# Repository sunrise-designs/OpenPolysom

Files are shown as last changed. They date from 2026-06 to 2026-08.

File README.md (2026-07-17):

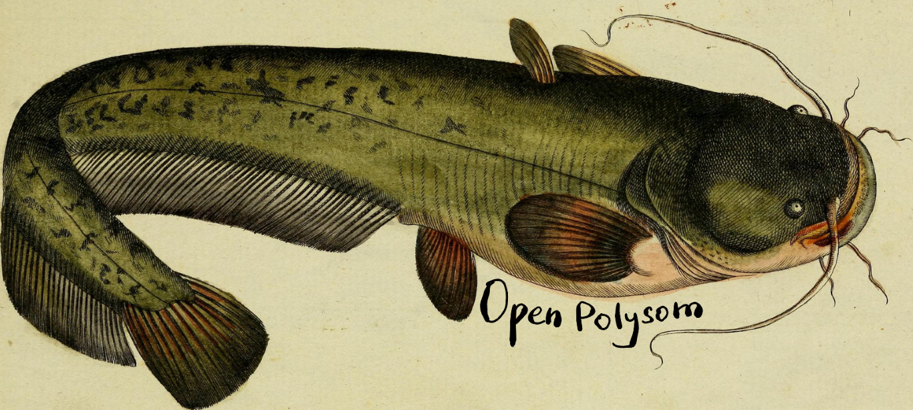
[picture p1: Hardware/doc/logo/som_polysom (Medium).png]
OpenPolysom


OpenPolysom
===========================

This is an open-source Polysomnography (PSG) physical device and analysis software. It performs what is know as a sleep study.

It runs on an ESP32 microcontroller, and collects these signals from a patient:
- [Respiratory Inductance Plethysmography (RIP)](#baseline-removal-from-the-rip-signal---the-chest-belts)
- [Nasal air flow rate](#air-flow-signal-processing)
- RR intervals (heart rate)
- Sound recording for [snoring detection](#snoring-classification-and-feature-extraction)
- Acceleration data from the leg sensors to [detect leg twitching](#accelerometer-data-processing)

New! Some real recordings:
===========================
[A somewhat truncated 2 hours of real sleep data - 17 July 2026](https://polysom.netlify.app/index.html?meta=studies%2Fbiometric_2026-07-16_23-00-00%2Fmeta.json)

Why do this?
===========================
It's about creating an _accessible, rapid_ diagnostic pathway for sleep disorders. Many, many people suffer from sleep disorders, breathing-related ones in particular. They have a significant effect on the quality of life, safety (falling asleep while driving) and serious long-term adverse health effects.
The current diagnostic process is abysmally slow on the NHS. There are private routes, but they are financially prohibitive for most.

It's hard to diagnose because:
- Most of the time, the sufferer is unaware of the problem (they only know they are groggy and tired)
- Partners don't know how to tell "normal" snoring, if there's such a thing, from a serious breathing-related sleep disorder
- It's seen as a "specialist" subject in the NHS, and GPs receive hardly any training in this field. They are quick to dismiss fatigue-related complaints
- Even once the person starts looking for a cause, the different avenues to explore are bewildering, expensive, and full of marketing hype
- There is not a streamlined diagnostic pathway, or "one-size-fits-all" solution, because of individual anatomy, neurological comorbidities, lifestyle and so on

What does this aim to do?
===========================
Firstly, this is not a replacement for a qualified medical opinion and treatment.
However, this seeks to:
- Raise awareness. There's not enough awareness around the variety of sleep disorders in the population. There have been huge campaigns around cancers, heart health (which is fantastic), but not this, yet
- Open source, forever. The main, explicit intention of this project is to always remain fully open source, software and hardware
  This means that anyone with enough knowledge can look at data, contribute, validate and build the OpenPolysom
- It aims to be simple enough for a layman to use, but powerful enough for advanced research and clinical diagnostics
- Affordable. There are great polysomnography solutions out there, sure. But they are very expensive, proprietary, and generally only accessible to
state healthcare systems or private clinics. The goal of this project is to be financially affordable to anyone

What is this going to look like?
===========================
The eventual goal is to have an easy-to-use, reusable, affordable polysomnography device and diagnostic infrastructure.
- A patient receives the device, or even builds it themselves
- They wear it for one or more nights
- Quality pre-processed data is recorded onto the device (removable SD card)
- There could be a few ways to analyze the data:
    - Send it to a specialist doctor or a clinician
    - Ask for advice on peer-to-peer forums like Apnea Board
    - Some combination of local and cloud-based algorithm can detect features of a number of breathing-related sleep disorders, like Obstructive Apnea, Central Apnea, UARS, and so on
- The strength of this project is pulling together various bits of science which are out there, but disjoint and difficult to find and use. It aims to make a comprehensive assessment of the data, find a possible problem (if any) and at least suggest possible treatment pathways. This is in no way a substitute for qualified medical advice.

How can it detect sleep disorders?
===========================
It a basic level, it's not so difficult! (The following is a simplified version!)

- If you're snoring away, then you stop, your chest belts show that you are "paradoxically breathing", in other words heaving for air, but there's no airflow - you might have Obstructive Apnea. You tongue or soft palate have collapsed backwards and blocked your airway. Your blood oxygen will also drop.
- There's no airflow, _and_ the chest belts show no movement. Your brain simply "forgot" to breathe! That's Central Apnea. Your blood oxygen wil also drop.
- Your blood oxygen does not drop appreciably, but your heart rate spikes significantly at times during your sleep. Your body has become quite sensitive to "breathing effort", and even though your airway isn't fully obstructed, your sleep is fragmented enough to make you feel terrible. This might be Upper Airway Resistance Syndrome (UARS). You might a completely "healthy" score on an official sleep apnea scale, but this is still a very serious problem!
- Your breathing might be fine, but you twitch lots in your sleep (this can be detected by an accelerometer). This could be Periodic Limb Movement Disorder (PLMD). This can also make you feel very tired.
- You might have none of the above, but you wake up gasping, talking and screaming in your sleep. You might be suffering from nightmares!
- And so on!

The point it, it takes a confluence of all the different signals recorded by the polysomnography device to steer the diagnosis in the correct direction. Recording just one or two things usually is not enough.

Challenges to solve
===========================
## Medical device compliance

There is no getting around the fact that this is a Medical Device, likely class B. There is no point in simply providing a heap of dry statistics and numerical metrics from the recorded signals - 99% of users without a very specialist skill set would not be able to interpret them. This isn't a "wellness" device. The interpretation is the whole point of the OpenPolysom, being able to cautiously point the user in the right direction on their path to the eventual resolution of their sleep problems.
This lands it firmly in the regulated territory. Therefore, this system, software and hardware alike, will be designed with IEC 62304 (Medical Software) in mind. The intent is to keep the code which extracts the dry metrics completely separate from the code which makes any interpretation of those metrics.

## Accelerometer data processing
I am currently using two accelerometers attached near the ankle to both legs to detect leg twitching and decide whether PLMS (Periodic Limb Movements of Sleep) or PLMD (Periodic Limb Movement Disorder) is present. The American Academy of Sleep Medicine (AASM) scoring criteria are fairly straightforward to interpret, but for an accurate count the acceleration due to twitching (sudden movement followed by return to the same leg position) should be distinguished from the acceleration due to the position change. This will be determined by the angle between the two baseline positions $q1$ and $q2$: $\Delta q = q_2 \otimes q_1^{-1}$ being below a certain threshold. (note: for advanced clinical studies, Leg Movement events are detected with Electromyography (EMG), because isometric contractions which do not result in physical movement also count. The accelerometers is a temporary proxy which is easier to setup and more robust)

## Baseline removal from the RIP signal - the chest belts

The plan is to achieve that using a combination of Qualitative Diagnostic Calibration (QDC) variant (Marvin Sackner, 1989) and Adaptive Iteratively Reweighted Penalized Least Squares (airPLS)

## Snoring classification and feature extraction

The end game would be to achieve accurate classification of anatomical snoring site according to the VOTE (Velum, Oropharynx, Tongue base, and Epiglottis). This could be achieved using MFCC/Mel feature extraction, then a fast real time ML model trained on the MPSSC (Munich-Passau Snore Sound Corpus) data.

## Air flow signal processing

I have not yet recorded a sample signal, but I am guessing there will be pretty standard noise filtering involved

The wiki — an LLM-first knowledge base
===========================
The in-depth documentation lives in an **LLM wiki**: a structured knowledge base written first for AI coding agents to read as working context, and second for humans. It is deliberately [`llms.txt`](https://llmstxt.org/)-shaped — a curated *map* of the project (architecture, data formats, signal processing, settled decisions, roadmap, coding standards) rather than an exhaustive dump — so an agent (or a person) reads the index first and then opens only the pages a task needs. The same Markdown is browsable as a website.

- **Browse it online:** https://sunrise-designs.github.io/OpenPolysom/
- **Read the source:** [`wiki/INDEX.md`](wiki/INDEX.md) — start here
- **Jump straight in:** [architecture](wiki/knowledge/architecture.md) · [data formats](wiki/knowledge/data-formats.md) · [roadmap](wiki/state/roadmap.md)

The Markdown in [`wiki/`](wiki) is rendered to a static site with [Quartz](https://quartz.jzhao.xyz/) and published to GitHub Pages (build: [`web/build.sh`](web/build.sh)).

What hardware does this expect
----------------------------
The hardware is currently a breadboard prototype, however a custom PCB is being developed in Kicad. See [hardware](/Hardware) folder.

The breadboard features (for now)
- LDC1612 inductance-to-frequency sensor on I2C bus with address 0x2B
- SDP800-125Pa Digital DP sensor (±125 Pa) (I2C address 0x25 or 0x26)
- Two MMA8451 accelerometers (with different I2C addresses)
- Polar H9 heart rate sensor via BLE

How to build
----------------------------
This is work in progress as project is developing fast.

The basic dependencies are:
- Python
- npm
- esp-idf (v 6.0 onwards)
- Rust (upcoming)

How to use
----------------------------
See this [brief guide](how%20to%20use.md)

Why a Som?
===========================
"Som" is a shorthand for polysomnography, and "Som" in Russian is a Wels catfish, _Silurus glanis_. I think it looks cool and terrifying in equal measure. Its whiskers also make me think of all the various probes and electrodes which feature on a polysomnography machine.

Disclaimer
===========================
This software is for informational and educational purposes only. It is not a medical device and is not intended to diagnose, treat, cure, or prevent any disease or sleep disorder.

Not Professional Advice: The outputs generated by this software should not be used as a substitute for professional medical advice, diagnosis, or treatment.

Consult a Physician: Always seek the advice of a qualified healthcare provider with any questions you may have regarding a medical condition.

No Liability: The developers and contributors provide this software "as is" and are not responsible for any actions taken based on its results.

References and inspiration
===========================
This software uses (heavily modified)
https://github.com/Seeed-Studio/Seeed_LDC1612

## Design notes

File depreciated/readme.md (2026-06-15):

Moving Windows-related stuff here. Because the code is running on Raspberry Pi, I don't want to spend time supporting Windows, for now, as Linux is a much better fit for this

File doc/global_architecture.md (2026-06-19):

There are two main components to this project:
1. Hardware data acquisition. It runs on a bespoke PCB board with ESP32-S3 microcontroller (WIFI/BLE/512KB SRAM, 384KB ROM, 8MB PSRAM, 8MB Flash memory)
2. Mixed local and cloud-based signal processing and visualization

I need help to decide on the architecture and data flow of the component 2, the data pipeline once it leaves the device.

The plan so far is:
1. ESP32 saves the various sampled signals (heart rate, sound, breathing, movement, EEG, etc) to an SD card. A simple proprietary binary format, which minimizes SD Card FTL Thrashing, will be used. The embedded code will be in C++
2. A python codebase ingests the binary data, and saves it to an intermediate format: Zarr binary file for high-density data, and a sidecar .json file for sparse metadata (like patient data, time of the experiment, settings and so on). Minimum processing happens at this stage.
3. In a second step, a signal processing Python codebase performs signal analysis on the data. This could become quite complex, incorporating elaborate DSP, and possibly ML and AI components. This will be the heart of the Polysom, it must be tightly version controlled, unit tested, and auditable. It will save the processed results to a new Zarr file (so that the raw data is preserved for auditability) and the results metadata .json file.
4. A Typescript codebase generates a web page which displays the charts via Apache ECharts, using HTTP Range Requests to enable responsive viewing of large datasets, and the associated metadata from the sidecar .json file(s)

Questions:
1. Does this sound sane?
2. Is ECharts the best option? Is there anything better/more performant/easier to use? Code Maintainability is very important.
2. Report generation in .pdf file format is very important. The current trade-off is to save the charts in a raster format, and combine them into a structured .pdf file where the metadata is selectable, bookmarked, and search-able. What are other potential options for this, if better ones exit?
3. This needs to be cross-platform as much as possible
3. Ideally, this should run locally, as well as on the web, in an air-gapped environment. Can the required infrastructure for this data flow (Python + packages, npm, etc) be realistically packaged into Windows, Linux and Mac installers?

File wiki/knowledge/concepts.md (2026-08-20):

---
title: PSG & Pipeline Concepts (Glossary)
domain: knowledge
status: living
updated: 2026-08-20
summary: A concise glossary of the polysomnography, sleep-disorder, signal and data-tech terms used across the ProtoSom wiki and codebase.
---

# PSG & Pipeline Concepts

A working glossary for ProtoSom. It defines the sleep-medicine terms behind the
signals we capture and the data-tech terms behind how we store and show them.
For *what we do* with these, see [signal processing](signal-processing.md),
[data formats](data-formats.md), [hardware](hardware.md) and the
[viewer](viewer.md); for *why* a thing is the way it is, see
[decisions](../state/decisions.md).

---

## Polysomnography (PSG)

**Polysomnography (PSG)** — a multi-signal sleep study: recording several
physiological channels simultaneously through a night's sleep so that breathing,
cardiac, movement and (here) acoustic events can be scored together. ProtoSom is
an open-source proof-of-concept PSG; no single channel diagnoses anything — it
takes a *confluence* of signals to steer a finding (`README.md:62`). It is
**not a medical device** (`README.md:134`).

The signals ProtoSom records ([hardware](hardware.md), `README.md:8`):
Respiratory Inductance Plethysmography (RIP, two belts), nasal airflow, heart
rate + RR intervals, wrist accelerometry, and audio for snore analysis.

---

## Sleep disorders & respiratory events

These are the *findings* the [Python processing](signal-processing.md) aims to
surface from the captured signals. Plain-language sketches per `README.md:51-60`.

- **Apnea** — a near-total cessation of airflow (conventionally ≥10 s in adults).
  Classified by what the RIP belts show:
  - **Obstructive apnea (OSA)** — *no airflow but the chest/abdomen belts still
    move*, often in opposite phase ("paradoxical breathing") as the body heaves
    against a collapsed upper airway (tongue/soft palate). Blood O₂ drops.
  - **Central apnea (CSA)** — *no airflow and no belt movement*: the drive to
    breathe is absent ("the brain forgot to breathe"). Blood O₂ drops.
  - **Mixed apnea** — a single event that begins central (no effort) and becomes
    obstructive (effort returns against a blocked airway), or vice versa.
- **Hypopnea** — a *partial* reduction in airflow (commonly ≥30% drop) sustained
  ≥10 s, paired with an O₂ desaturation and/or an arousal. The graded cousin of
  an apnea.
- **RERA (Respiratory Effort-Related Arousal)** — increasing breathing effort
  that ends in a cortical arousal but does **not** meet apnea/hypopnea
  thresholds. Visible as effort climbing on the RIP belts with airflow only
  mildly reduced.
- **UARS (Upper Airway Resistance Syndrome)** — repeated RERAs fragmenting sleep
  with *little or no O₂ desaturation*; the body becomes hypersensitive to
  breathing effort, often signalled by **heart-rate spikes** rather than
  desaturation. Can score "healthy" on a conventional apnea scale yet still be
  serious (`README.md:57`).
- **PLMD (Periodic Limb Movement Disorder)** — repetitive limb jerks in sleep
  that fragment it. Detected here from wrist accelerometry by AASM PLM scoring
  (see [PLM / AASM](#aasm-scoring-epochs--indices) and
  [`plans/removing accel baseline.md`](../../plans/removing%20accel%20baseline.md)).

---

## Captured signals

### Respiration

- **RIP (Respiratory Inductance Plethysmography)** — two inductive belts
  (Thoracic + Abdomen) whose inductance changes as the cross-sectional area of
  the ribcage/abdomen changes with breathing. ProtoSom reads them via an
  **LDC1612** inductance-to-frequency sensor at 50 Hz; the EDF+ header declares
  nanohenries but the channel actually carries pre-divided raw counts
  ([hardware](hardware.md)). Thoracic−Abdomen phase is the
  central/obstructive discriminator above.
- **Nasal airflow** — airflow rate measured by a differential-pressure sensor
  (**SDP800-125Pa**, ±125 Pa, 50 Hz). The "is air actually moving" channel that
  apnea/hypopnea scoring keys off. Expected to need standard noise filtering
  (`README.md:74-76`).
- **QDC (Qualitative Diagnostic Calibration)** — a Sackner (1989) method for
  combining the two RIP belts into a calibrated estimate of tidal volume / airflow
  surrogate. Used here alongside **airPLS** for RIP baseline removal
  (`README.md:66-68`; see [signal processing](signal-processing.md)).
- **airPLS (Adaptive Iteratively Reweighted Penalized Least Squares)** — an
  iterative baseline-fitting algorithm (originally for spectra) that estimates and
  subtracts a slow drifting baseline while preserving the breathing waveform on
  top. ProtoSom's planned RIP baseline-removal step (`README.md:68`).

### Cardiac

- **Heart rate (HR)** — beats per minute. **Not a captured channel**: the
  ESP32-C6 has no `HR` channel. Heart rate is something to *derive* from the ECG
  trace, not a signal read off a sensor.
- **RR interval** — the time (ms) between successive R-peaks of consecutive
  heartbeats; the beat-to-beat timing series. A 2.5 Hz channel on the ESP32-C6,
  but currently a **dead channel logging zeros** — the device has no R-peak
  detection ([hardware](hardware.md)). Note: *RR interval* (cardiac) is distinct
  from *RR = respiratory rate* in other PSG literature — in ProtoSom "RR" means
  the cardiac interval.
- **HRV (Heart Rate Variability)** — variability of the RR-interval series; a
  proxy for autonomic state. Sleep-disordered breathing perturbs it, and HR/HRV
  spikes are a key UARS tell.
- **RMSSD (Root Mean Square of Successive Differences)** — the standard
  time-domain HRV metric: the RMS of the differences between successive RR
  intervals. Computed by `compute_hrv` in
  [`src_python/signal_processing.py`](../../src_python/signal_processing.py).
- **ECG (electrocardiogram)** — the raw cardiac electrical trace; an AD8232 ADC
  channel (`ECG`, 100 Hz) and the device's **only** cardiac source. R-peaks (and
  hence RR intervals, and hence HRV) would be derived from it — that derivation is
  not yet built on-device or host-side.

### Movement

- **Accelerometry** — 3-axis acceleration (Accel0X/Y/Z, Accel1X/Y/Z) from two
  MMA8451 accelerometers on the ESP32-C6, reported in **mg at 50 Hz**. Two of them
  gives the bilateral (per-leg plus combined) scoring standard PSG practice wants.
  Used to detect limb movement for PLMD; baseline drift (posture changes) is
  stripped by rolling-median subtraction before PLM detection
  ([`plans/removing accel baseline.md`](../../plans/removing%20accel%20baseline.md)).
- **Vector magnitude** — `sqrt(ax² + ay² + az²)` per sample over the
  **baseline-removed** (zero-centred) axes: the three accel axes collapsed into one
  activity signal for limb-movement detection. (The `−128` centring seen in older
  notes belonged to the retired uint8 byte-log format, not to the current mg scale.)

### Acoustic (snoring)

- **Snoring** — sound produced by vibration of soft tissue in the upper airway
  during sleep; ProtoSom records audio (high-quality USB mic, `README.md:89`) as a
  separate channel for classification, not just detection.
- **VOTE** — a clinical scheme naming the *anatomical site* of upper-airway
  vibration/collapse: **V**elum, **O**ropharynx (lateral walls), **T**ongue base,
  **E**piglottis. The snore-classification end-goal is to label the VOTE site from
  the sound (`README.md:70-72`).
- **MFCC (Mel-Frequency Cepstral Coefficients) / Mel** — audio features on the
  **Mel scale** (a perceptual, roughly-log frequency scale). MFCCs are a compact
  spectral summary widely used in audio ML; planned as the snore feature set
  feeding a model trained on the **MPSSC** (Munich-Passau Snore Sound Corpus)
  (`README.md:72`).
- **Spectrogram** — a time × frequency × intensity image of a signal (here, the
  audio). [Python processing](signal-processing.md) precomputes the spectrogram
  array into the [working store](data-formats.md) so the
  [viewer](viewer.md) (wavesurfer.js audio pane) can render it without recomputing.

---

## AASM scoring, epochs & indices

- **AASM** — the American Academy of Sleep Medicine, whose *Scoring Manual* (we
  reference v2.6) defines the standard rules for scoring sleep events. ProtoSom's
  PLM counting implements its published criteria
  ([`plans/removing accel baseline.md`](../../plans/removing%20accel%20baseline.md)).
- **Epoch** — the fixed time window sleep is scored in, conventionally **30 s**.
  Each epoch gets a sleep stage; events are tallied across epochs.
- **Hypnogram** — the staged timeline of a night's sleep (the sequence of sleep
  stages across all epochs), the classic step-plot summary of sleep architecture.
- **LM (Limb Movement)** — a single qualifying limb movement: amplitude ≥ a
  threshold above baseline, duration **0.5–10 s** (25–500 samples @ 50 Hz; longer
  = posture change, not a jerk).
- **PLM (Periodic Limb Movement)** — LMs occurring in a **series of ≥4** with
  onset-to-onset gaps of **5–90 s**. Counted by `count_plm` per AASM rules
  ([`plans/removing accel baseline.md`](../../plans/removing%20accel%20baseline.md)).
- **GPC (Gross Position Change)** — a whole-body posture change (rolling over,
  turning) as opposed to a limb jerk. Swings a far larger amplitude than an LM
  and, unlike an LM, leaves the accelerometer **pointing somewhere new** — that
  rotation relative to gravity, not the amplitude, is what reliably tells the two
  apart. GPCs are excluded from LM/PLM scoring; see
  [signal processing § 2b](signal-processing.md) and
  [decisions § S11](../state/decisions.md). ProtoSom-specific terminology (the AASM
  manual speaks only of movements "longer than 10 s" being posture change), coined
  by Dmitry.
- **Index (events/hour)** — events normalised to recording duration:
  - **AHI (Apnea-Hypopnea Index)** — (apneas + hypopneas) ÷ sleep hours; the
    headline severity number for sleep-disordered breathing.
  - **RDI (Respiratory Disturbance Index)** — like AHI but *including RERAs*, so
    it catches UARS-type fragmentation that the AHI misses.
  - **PLMI (PLM Index)** — PLMs ÷ recording hours; adult diagnostic threshold
    **≥15/hour**.

---

## Data & technology terms

These describe how ProtoSom stores and serves the data across its three-language
pipeline (**C++ ingest → Python processing → the TS web app**); see
[data formats](data-formats.md) and [architecture](architecture.md).

- **EDF / EDF+** — *European Data Format* (and the `+` revision adding
  annotations/events), the de-facto open standard for biosignal recordings. EDF+
  is ProtoSom's **raw anchor** for biosignals — what the device emits, immutable —
  and is read via **edflib**. EDFBrowser opens it directly, which is why it's also
  the **clinical export** format (`README.md:13`).
- **BDF+** — BioSemi Data Format, an EDF+ variant using **24-bit** samples
  (vs EDF's 16-bit). Reserved for future higher-resolution EEG.
- **FLAC** — *Free Lossless Audio Codec*. The **raw anchor** for the audio
  channel: a lossless, time-anchored sidecar to the EDF+ biosignals.
- **Zarr** — a chunked, compressed, language-neutral array store. It is **the
  Zarr boundary** of the pipeline: [C++ ingest](architecture.md) writes the raw
  Zarr, [Python processing](signal-processing.md) reads it and writes the derived
  Zarr + JSON metadata, and the [TS web app](viewer.md) *reads* it (never writes).
  The **working store** is one Zarr group per recording — each dense signal its
  own array — plus JSON sidecars (`events.json`, `meta.json`). We pin **Zarr v2 +
  Blosc(zstd, shuffle)** with no Python-only filters so all three languages
  interoperate (see [decisions](../state/decisions.md)).
- **Chunking** — splitting a Zarr array into fixed-size blocks (here, along the
  time axis) so a reader can fetch just the slice it needs without loading the
  whole array. The basis of the windowed read the [viewer](viewer.md) uses.
- **Decimation** — reducing a signal's sample count to what a target needs (e.g.
  screen-resolution for the visible window). "The data the chart needs" is the
  visible window at screen resolution, **not** the whole recording.
- **LTTB (Largest-Triangle-Three-Buckets)** — a downsampling algorithm that picks
  the points which best preserve a line's *visual shape*, so a decimated chart
  still looks right. Used by the [viewer](viewer.md)'s charting (ECharts).
- **The slicing server** — a thin TS server that reads the Zarr and serves the
  browser screen-resolution windows over an HTTP windowed API
  (`/window`, `/spectrogram`, `/meta`, `/events`) once recordings outgrow a
  browser-direct read. Same reading code, just moved server-side; it decimates
  on-the-fly (precomputed pyramids later, without changing the viewer). See
  [architecture](architecture.md) and [viewer](viewer.md).
- **Provenance / content-hash** — the **raw anchor** is content-hashed and never
  modified; every regenerable **derived layer** product is stamped with provenance
  in `meta.json` so any result can be traced back to its inputs (the IEC 62304
  reproducibility/auditability aspiration, `README.md:83-85`;
  [standards/coding](../standards/coding.md)).

---

## See also

- [architecture](architecture.md) — the four-stage pipeline and three-layer data model.
- [data formats](data-formats.md) — EDF+/FLAC raw anchor, Zarr working store, EDF+ clinical export.
- [signal processing](signal-processing.md) — baseline removal, PLM, HRV, snore, airflow.
- [hardware](hardware.md) — sensors, channels, sample rates, dtypes.
- [viewer](viewer.md) — the TS web app, charts, spectrogram pane.
- [decisions](../state/decisions.md) — settled choices and open forks.

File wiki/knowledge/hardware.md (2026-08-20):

---
title: Hardware & C++ Ingest
domain: knowledge
status: living
updated: 2026-08-20
summary: The acquisition device (the ESP32-C6 unit), its sensors, the exact 11-channel EDF+ layout, the I2C data paths that feed the C++ ingest side, and the opt-in Wi-Fi rt_stream component that serves those same samples live.
---

# Hardware & C++ Ingest

The acquisition device that sits at the head of the [pipeline](../knowledge/architecture.md):
**device → ingest → signal-processing → web app**. It is owned by Dmitry and writes
**EDF+** via [edflib](https://gitlab.com/Teuniz/EDFlib) — the **raw anchor** for biosignals
(see [data formats](../knowledge/data-formats.md)). EDF+ is the device output; **C++ ingest**
then converts it into the **raw Zarr** of the **working store**. Everything on this page is the
C++ ingest side of the [three-language boundary](../state/decisions.md) (C++ ingests, Python
processes, the TS web app presents; they meet at the **Zarr boundary**).

> **The hardware runs entirely on the ESP32-C6.** Its 11-channel EDF+ is the **only** raw anchor
> the pipeline targets.

---

## 1. The ESP32-C6 unit — 11-channel EDF+

A [Seeed Studio XIAO ESP32-C6](https://wiki.seeedstudio.com/xiao_esp32c6_getting_started/) on a
bespoke breadboard (a KiCad PCB is in progress — see the `Hardware/` folder). The firmware
([`ESP32-C6-heart-idf`](../../ESP32-C6-heart-idf/)) keeps the radios off for a normal night's
recording, to cut power consumption. **BLE is not compiled in at all**; Wi-Fi is compiled in but
**off unless real-time streaming has been enabled for the device** (§ [live streaming](#3-live-sample-streaming--the-rt_stream-component)
below, and [decisions § S12](../state/decisions.md)):

- **Time sync** — a custom serial protocol (`tools/set_time.py`) instead of NTP, backed by a
  **DS3231** RTC on the I2C bus.
- **Display** — an **SH1106** I2C OLED for local status.
- **Data offload** — the Wi-Fi File Access Point was removed; EDF+ logs are read directly off the
  SD card. Live *streaming* is a different feature and does not offload files.

Samples are written **digitally** (`edfwrite_digital_samples`,
[`logger.cpp:548`](../../ESP32-C6-heart-idf/components/logger/logger.cpp)), so the raw Zarr arrays
produced from this file carry the attr `storage=digital`. Data records are **10 s**
(`RECORD_DURATION_S`, [`logger.h:9`](../../ESP32-C6-heart-idf/components/logger/include/logger.h)),
set via `edf_set_datarecord_duration` at [`logger.cpp:469`](../../ESP32-C6-heart-idf/components/logger/logger.cpp).

Channel table (exact, from the `SigDef` table at
[`logger.cpp:473–485`](../../ESP32-C6-heart-idf/components/logger/logger.cpp)):

| # | Label | Transducer | Rate | Phys. dim | Digital min/max | Phys. min/max |
|---|---|---|---|---|---|---|
| 0 | `Thoracic` | LDC1612 CH0 — thoracic RIP belt | 50 Hz | `counts` | −32767 / 32767 | −1,000,000 / 1,000,000 |
| 1 | `Abdomen`  | LDC1612 CH1 — abdomen RIP belt  | 50 Hz | `counts` | −32767 / 32767 | −1,000,000 / 1,000,000 |
| 2 | `Flow` | SDP800-125Pa | 50 Hz | `mbar` | −32767 / 32767 | −100 / 100 |
| 3 | `ECG` | AD8232 ADC0 | 100 Hz | `ADC` | 0 / 4095 | 0 / 4095 |
| 4–6 | `Accel0X/Y/Z` | MMA8451 ch0 | 50 Hz | `mg` | −8192 / 8191 | −2000 / 2000 |
| 7–9 | `Accel1X/Y/Z` | MMA8451 ch1 | 50 Hz | `mg` | −8192 / 8191 | −2000 / 2000 |
| 10 | `RR` | `N/A` — **no live source** | 2.5 Hz | `ms` | 0 / 2000 | 0 / 2000 |

> `edf_set_samplefrequency()` takes **samples per data record**, not Hz — the effective rate is
> `samplefrequency / record duration`. `logger.cpp:494` computes it as
> `lround(rate * RECORD_DURATION_S)`; the `lround` guards `RR`'s fractional **2.5 Hz**
> (25 samples/record) against float truncation landing on 24.

### Cardiac: ECG only — `RR` is a dead channel

The **AD8232** analog front-end is read directly off **ADC channel 0** and genuinely sampled at
100 Hz. It is the device's **sole cardiac source**.

The `RR` channel exists in the EDF+ layout but has **no live source** — its transducer is literally
`"N/A"` and it logs zeros. On-device R-peak detection is not implemented, so RR intervals (and
therefore [HRV](../knowledge/signal-processing.md)) have no genuine input from this device today.
Anything the [Python processing](../knowledge/signal-processing.md) computes from `RR` on a current
recording is computed from zeros. Wiring RR up means either detecting R-peaks on-device from the
ECG channel, or deriving them host-side in [Python processing](../knowledge/signal-processing.md)
from the 100 Hz `ECG` array — the latter fits the language boundary better and is the likelier path.

There is no `HR` channel on the ESP32-C6 at all — heart rate is a derived quantity, not a captured one.

### Sensors on the I2C bus

- **LDC1612** (Seeed) — dual-channel inductance-to-digital converter; drives the two **RIP**
  (respiratory inductance plethysmography) belts on CH0/CH1.
- **SDP800-125Pa** (Sensirion) — differential pressure sensor for nasal/oral **airflow**, ±125 Pa.
- **MMA8451 ×2** (NXP) — two 3-axis accelerometers at different I2C addresses, reported in **mg**
  at 50 Hz, giving the bilateral (two-leg) limb-movement channels the AASM PLM scoring needs.
- **DS3231** — battery-backed RTC, so the recording start datetime survives a power cycle.
- **SH1106** — I2C OLED for local status.
- **AD8232** (Analog Devices) — single-lead **ECG analog front-end**, read via ADC (not I2C).
  [Datasheet](https://www.analog.com/media/en/technical-documentation/data-sheets/ad8232.pdf).

> [!warning] RIP physical-range quantization — open issue
> Thoracic/Abdomen declare a physical range of **±1,000,000 nH** against a 16-bit digital sample
> (65,536 levels), so the LSB is ~30 nH and almost all 16 bits are headroom that never fills.
> The firmware works around this **on the digital side** rather than by fixing the header: raw
> LDC1612 counts are divided by a per-channel constant (`THORACIC_DIVISOR 15`,
> `ABDOMEN_DIVISOR 11`, [`logger.cpp:194–195`](../../ESP32-C6-heart-idf/components/logger/logger.cpp))
> so each channel's breathing swing occupies more of the digital range. Those divisors were derived
> from **one night's** peak non-clipped swing with ~2× headroom — deeper breathing on a different
> patient or night could still saturate, and needs re-tuning. The declared physical range is
> untouched, so the physical→digital map in the header no longer describes nanohenries. Tracked as
> open fork **O3** in [decisions](../state/decisions.md).

### RIP baseline capture and its reboot behaviour

`logger.cpp` writes Thoracic/Abdomen as `raw − baseline`, capturing the baseline **20 minutes**
into the recording (`BASELINE_DELAY_S = 1200`, [`logger.cpp:243`](../../ESP32-C6-heart-idf/components/logger/logger.cpp))
averaged over 1 s (`BASELINE_AVG_SAMPLES = 50` @ 50 Hz), once belt-donning settles. Before that
point samples are written against a zero baseline — raw counts, effectively uncalibrated.

That uncalibrated window used to repeat after **every** reset. Since 2026-07-19 the captured
baseline is mirrored into RTC memory (`RTC_NOINIT_ATTR` + a magic word) and restored whenever
`esp_reset_reason()` is anything other than `ESP_RST_POWERON` — a panic/WDT/brownout reboot
mid-night resumes calibrated immediately, because the belts did not move across the reset.
A power-on still captures fresh, since unplugging the device in practice means the belts came
off. `RTC_NOINIT_ATTR` is load-bearing: `.rtc.data` (`RTC_DATA_ATTR`) is a *loaded* segment the
bootloader re-initialises on every non-deep-sleep boot, so it would not survive a panic reset.

The choice is recorded per-recording in the JSON sidecar's `ldc_baseline` block
(`ch0`/`ch1`/`valid`/`reused`/`reset_reason`/`delay_s`) — the
[zarr schema spec § 6.5](../planning/zarr-schema-spec.md) flags this on-device transform as
provenance that must not be lost. `reused: true` means the recording inherited the previous boot's
baseline rather than capturing its own — an ingest-visible fact, since a restored baseline predates
the recording's own start time.

### The JSON sidecar the device writes

Alongside the `.edf`, `write_json_sidecar` ([`logger.cpp:351`](../../ESP32-C6-heart-idf/components/logger/logger.cpp))
emits a `.json` carrying `device_uid` (derived from the MAC), `recording_start_time` /
`recording_end_time`, `timezone`, a `sensors[]` presence + sample-rate list, and the `ldc_baseline`
block above. This is **device-level** provenance and is distinct from the `meta.json` that
[Python processing](../knowledge/signal-processing.md) writes into the working store; C++ ingest
should fold it into the latter.

> **No EDF+ header provenance, and no PII.** The C6 firmware sets
> **no equipment string, no patient name, and no birthdate** — there is no `edf_set_equipment` /
> `edf_set_patientname` / `edf_set_birthdate` call anywhere in the firmware, and no git hash is
> compiled in. Two consequences, pulling opposite ways: the raw anchor is **PII-free by
> construction**, which removes the "hashed anchor embeds a patient name" conflict entirely (see
> [privacy](../standards/privacy.md)); but firmware build provenance is **absent**, not merely
> degraded, so an EDF+ from this device cannot currently be traced to the build that produced it.
> Restoring a full-SHA + dirty-flag stamp is owed — see [zarr schema spec § 6.5](../planning/zarr-schema-spec.md).

---

## 2. Provenance & the Zarr boundary

The device emits **EDF+** as the immutable **raw anchor**. C++ ingest (Dmitry) reads that EDF+ via
edflib, converts each dense signal into a chunked **raw Zarr** array (each channel its own array,
chunked along time) plus extracted header metadata, and writes the **working store**. The
`storage=digital` attr records that `edfwrite_digital_samples` produced the source samples, so
[Python processing](../knowledge/signal-processing.md) and the TS web app apply the EDF+
physical/digital scaling correctly. From there Python reads raw Zarr → writes the **derived layer**
+ `events.json` + `meta.json`; the [TS web app](../knowledge/viewer.md) only **reads** Zarr. See
[architecture](../knowledge/architecture.md) and [data formats](../knowledge/data-formats.md).

With a single acquisition device there is **one clock**, so every channel in the recording shares
one time origin and no cross-device offset + skew model is needed.

---

## 3. Live sample streaming — the `rt_stream` component

[`components/rt_stream`](../../ESP32-C6-heart-idf/components/rt_stream/) serves the samples
`logger.cpp` writes to the EDF+ over a **Wi-Fi WebSocket**, so the signals can be watched while a
recording runs — the [viewer](viewer.md)'s RT mode. It exists because a bad montage (a lifted
electrode, an unplugged belt) is currently only discoverable the next morning.

**Why wireless, not the USB link that is already there.** The AD8232 puts electrodes on the
patient. A USB tether to a mains-powered host is a leakage-current path; a battery-powered device
streaming over its own access point is not. Galvanic isolation is the reason this feature reopened
the no-Wi-Fi choice rather than riding the existing serial command channel — see
[decisions § S12](../state/decisions.md).

- **Off by default, per-device opt-in.** An NVS flag, set over the same serial command server as
  time sync (`tools/set_rt_stream.py`, magic `0xA5 0x5B`), applied on the next boot. Changing it
  live would put radio TX current in the path of the SD writes. The radio also stops itself after
  `RT_STREAM_IDLE_TIMEOUT_S` (10 min) with no client. An unattended night therefore keeps exactly
  the old power profile.
- **SoftAP** `ProtoSom-<last 3 MAC bytes>`, WPA2 with a per-device password derived from the MAC.
  Both are shown on the OLED's row 7, alternating, since there is nowhere else to discover them.
  STA mode is a `config.h` option for a lab setup.
- **The sample path never blocks.** `rt_stream_push_50hz`/`_ecg` are called from `sensor_task`
  beside `logger_record*()` and do a zero-timeout `xQueueSend`: a full queue **drops the frame and
  counts it**. Recording integrity outranks streaming, so a stalled radio can cost the viewer a
  visible gap but never delays the card. A lower-priority task drains the queue, formats one JSON
  frame per 100 ms with `snprintf` into a static buffer (no heap in the send loop), and broadcasts
  it.
- **Streamed values are the recorded values.** Thoracic/abdomen/flow are not what the sensor
  reported — they are baseline-subtracted, divided and scaled on the way to the EDF+. Rather than
  re-derive them, `rt_stream` calls `logger_thoracic_digital()` / `logger_abdomen_digital()` /
  `logger_flow_digital()`, which `logger_record()` itself uses. One implementation, so a streamed
  data point is the same integer that reaches the card.
- **Build cost:** the Wi-Fi + HTTP stack takes the binary from ~373 KB to ~1.15 MB, still 63% free
  in the 3 MB `factory` partition. No partition changes were needed.

The wire format and the reader side are documented in [viewer § RT vs batch](viewer.md).

## 4. Future hardware direction

- **OpenPolysom** is the project name; the ESP32-C6 breadboard unit is its current reference
  build, with a KiCad PCB in progress (`Hardware/`).
- **RR from ECG** — the highest-value missing link, since HRV is a
  [UARS](../knowledge/concepts.md) signal and the channel is currently zeros (§1).
- **24-bit EEG** would move biosignals to **BDF+** (the raw anchor format already anticipated for
  this — see [data formats](../knowledge/data-formats.md)). The `Hardware/` folder already carries
  an `EEG.kicad_sch`.
- **Audio** — a microphone path (`Microphone.kicad_sch`) for the [FLAC snore
  sidecar](../knowledge/data-formats.md) is designed but not yet captured in firmware.
- A **full-lead wired ECG** path (AD8232 with RA/LA/RL) remains an option Dmitry has noted as
  higher-fidelity but harder to wear.

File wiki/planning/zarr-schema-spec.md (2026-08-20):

---
title: PSG-on-Zarr Schema Specification
domain: planning
status: snapshot
updated: 2026-08-20
summary: The concrete Zarr working-store + events + metadata schema and the EDF round-trip, rewritten 2026-07-19 against the single-device ESP32-C6 hardware.
---

> Note: the language split has since settled to **C++ ingest / Python processing / TS web app** (see [decisions](../state/decisions.md)). The Zarr schema, events, metadata, and round-trip below stand; treat any in-text language attributions as the design-time snapshot.
>
> **Single-device hardware.** The **ESP32-C6's 11-channel EDF+ is the sole raw anchor**, and the tables below are written against `logger.cpp`'s actual `SigDef`. Three structural consequences hold throughout: there is **one clock** (§6.4 carries no cross-device offset/skew model), **one `signals/` group**, and **every captured array is `storage="digital"`** (the firmware writes `edfwrite_digital_samples` exclusively — the attribute is retained for derived arrays and future producers).

# ProtoSom — PSG-on-Zarr Schema Specification (v0.1)

**Status:** proposal for Dmitry review. **Scope:** layer (2) of the three-layer data model — the unified working store, its events sidecar, its metadata/provenance manifest, and the EDF/BDF round-trip at the edges. **Audience:** the host-side data pipeline (Python) and Dmitry's host-side C++ tooling. The device firmware never writes Zarr.

---

## 1. Overview & the three-layer model

ProtoSom stores one sleep recording as a directory holding three layers. **Layer 1 (raw capture)** is whatever the device emits — EDF+ for biosignals, FLAC for audio — immutable and content-hashed; it is the provenance anchor and is never modified. **Layer 2 (unified working store)** is a single Zarr group per recording (every dense signal its own array, chunked along time), plus two JSON sidecars (`events.json` for sparse/typed annotations, `meta.json` for metadata + provenance + the 3-layer manifest); it is regenerable from layer 1 and is what the local slicing server reads and what the DSP reads/writes. **Layer 3 (clinical export)** is EDF+/BDF+ regenerated on demand for EDFBrowser interop; it is never stored. The on-disk shape:

```
2026-07-16_2300_protosom-c6/         # recording directory; recording_id = dir name
  meta.json                          # §6 — metadata + provenance + 3-layer manifest
  raw/
    biometric_2026-07-16_23-00-00.edf  # layer 1: immutable EDF+ (ESP32-C6, 11 ch), hashed
    biometric_2026-07-16_23-00-00.json # layer 1: the firmware's own device sidecar, hashed
    snore_16k.flac                   # layer 1: immutable FLAC (future), hashed + time-anchored
  working.zarr/                      # layer 2: one Zarr v2 group (§3)
  events.json                        # layer 2: sparse events/annotations (§5)
  export/
    clinical.edf                     # layer 3: regenerated, not committed (§7)
```

> **Reality check (state this to Dmitry up front).** The EDF→Zarr ingest and the Zarr→EDF export described here **do not exist yet**. Today's Python pipeline reads the EDF+ raw anchor directly, not via a raw Zarr; `export_zarr.py` writes single-chunk arrays with no calibration attributes. This spec defines the **target contract** and names what must be built (`ingest_edf.py`, `export_edf.py`, a DSP refactor). None of the round-trip or re-derivation guarantees are exercised by current code.

---

## 2. Zarr version + codec decision

**Decision: Zarr v2.** Rationale, tied to C++ library support:

- The binding constraint is the **intersection of the three C++ libraries the brief names**. The canonical [Zarr implementations registry](https://zarr.dev/implementations/) lists **z5 = v2 only, xtensor-zarr = v2 only, TensorStore = v2 + v3**. Choosing finalized Zarr v3 collapses the C++ reader set to **TensorStore alone** — exactly the single-library lock-in the brief flagged as the biggest risk.
- The "xtensor-zarr does v3" claim does not survive scrutiny: its last release (v0.0.7, 2021) implements the **abandoned pre-ZEP1 draft** (`.zr3` store, `meta/root/<name>.array.json`), whose layout is mutually unreadable with finalized v3's single `zarr.json` per node. The registry correctly classes it v2 for practical purposes.
- v3's only load-bearing advantage at our scale is `sharding_indexed` (avoids the "millions of tiny chunk files" problem). The brief's own design — server slices windows, pyramids added later — keeps per-night chunk counts modest (a 50 Hz channel over 8 h ≈ 480 chunks; see §3/§4 sizing), so sharding is **not needed for v0.1**. The v2→v3 migration is mechanical (re-encode arrays, same logical model), so this is a reversible bet; revisit if (a) per-night chunk-file counts cross ~10⁵ **and** (b) z5 is dropped as a candidate.

**Codec (every array, identical):** numcodecs **Blosc(cname=`zstd`, clevel=5, shuffle=`SHUFFLE`)** for integer arrays; `shuffle=BITSHUFFLE` for float arrays. Blosc+zstd+shuffle is the best ratio/speed combination for low-entropy physiological time-series and is implemented by all three C++ libs plus zarr-python. **`filters: null`** on every array (no numcodecs Delta/FixedScaleOffset/PackBits/Categorize — those are Python-only traps for the C++ readers; byte-shuffle gives the delta-like benefit portably). **`dimension_separator: "."`** pinned for maximum C++ reader compatibility. `shuffle` in a v2 `.zarray` is the **integer** `1` (SHUFFLE) / `2` (BITSHUFFLE), not the v3 string — a C++ writer must emit the integer.

---

## 3. Zarr group layout, dtypes, chunks, attributes

### 3.1 Worked tree (the ESP32-C6 11-channel recording + derived)

```
working.zarr/                       # .zgroup {"zarr_format": 2}; root .zattrs in §6.1
├─ signals/                         # device-captured biosignals (regenerable from raw EDF+)
│   ├─ thoracic     int16    rate 50   chunks (3000,)   storage=digital   mask=thoracic_mask
│   ├─ abdomen      int16    rate 50   chunks (3000,)   storage=digital   mask=abdomen_mask
│   ├─ flow         int16    rate 50   chunks (3000,)   storage=digital   mask=flow_mask
│   ├─ ecg          int16    rate 100  chunks (6000,)   storage=digital   mask=ecg_mask
│   ├─ accel0_x     int16    rate 50   chunks (3000,)   storage=digital   mask=accel0_x_mask
│   ├─ accel0_y     int16    rate 50   chunks (3000,)   storage=digital
│   ├─ accel0_z     int16    rate 50   chunks (3000,)   storage=digital
│   ├─ accel1_x     int16    rate 50   chunks (3000,)   storage=digital   mask=accel1_x_mask
│   ├─ accel1_y     int16    rate 50   chunks (3000,)   storage=digital
│   ├─ accel1_z     int16    rate 50   chunks (3000,)   storage=digital
│   └─ rr           int16    rate 2.5  chunks (1024,)   storage=digital   mask=rr_mask
├─ derived/
│   ├─ accel0_mag   float32  rate 50  chunks (3000,)   gap=NaN   (per-leg PLM input)
│   ├─ accel1_mag   float32  rate 50  chunks (3000,)   gap=NaN   (per-leg PLM input)
│   ├─ accel_combined_mag  float32  rate 50  chunks (3000,)  gap=NaN  (bilateral, headline)
│   ├─ hrv_rmssd    float32  irregular  time_array=derived/hrv_t   gap=NaN
│   ├─ hrv_t        float64  irregular  (seconds from t0)
│   └─ audio/
│       └─ snore_spectrogram  float32  2D [freq,time]  chunks (257, 512)
└─ pyramid/                         # multi-resolution; LAYOUT FIXED NOW, COMPUTED LATER (§4)
    ├─ thoracic/   1/ 2/ 3/ 4/ 5/   # each: int16 shape (n,2) last axis=[min,max]
    └─ ecg/        1/ 2/ ...
```

A single `signals/` group: with one acquisition device there is no second clock to segregate. All three accel magnitude traces are **derived**
(they are computed by [Python processing](../knowledge/signal-processing.md) from the six raw
axes), which is why the bilateral combined channel lives under `derived/` alongside the per-leg
ones — see [signal processing § 3](../knowledge/signal-processing.md).

### 3.2 Storage policy — the single normative table

There is no physical-vs-digital asymmetry at capture: `logger.cpp` writes **every** channel via
`edfwrite_digital_samples` (line 548), so the on-disk digital samples are exactly what the firmware
computed — no edflib requantization anywhere in the capture path. The per-array **`storage`**
attribute is retained regardless, because the *derived* layer holds calibrated float arrays and a
future producer may write physical doubles. This table is canonical; §5/§6/§7 reference it and do
not redefine dtypes.

Values are exact from the `SigDef` table at `logger.cpp:473–485`.

| Array | Source | Rate (Hz) | `storage` | Zarr dtype | digital_min/max | physical_min/max | unit | gap mechanism |
|---|---|---|---|---|---|---|---|---|
| `signals/thoracic` | LDC1612 CH0 | 50 | digital | int16 | −32767 / 32767 | −1e6 / 1e6 | `counts` (nominal nH — see O3) | mask array |
| `signals/abdomen` | LDC1612 CH1 | 50 | digital | int16 | −32767 / 32767 | −1e6 / 1e6 | `counts` (nominal nH — see O3) | mask array |
| `signals/flow` | SDP800-125Pa | 50 | digital | int16 | −32767 / 32767 | −100 / 100 | mbar | mask array |
| `signals/ecg` | AD8232 ADC0 | 100 | digital | int16 | 0 / 4095 | 0 / 4095 | ADC | mask array |
| `signals/accel0_x/y/z` | MMA8451 ch0 | 50 | digital | int16 | −8192 / 8191 | −2000 / 2000 | mg | mask array |
| `signals/accel1_x/y/z` | MMA8451 ch1 | 50 | digital | int16 | −8192 / 8191 | −2000 / 2000 | mg | mask array |
| `signals/rr` | **none — logs zeros** | 2.5 | digital | int16 | 0 / 2000 | 0 / 2000 | ms | mask array |
| **Future** `signals/eeg` (2D `[ch,time]`) | EEG ADC | 256 | digital | int32 | −8388608 / 8388607 | per montage | µV | mask array |
| **Future** `signals/spo2` | pulse-ox | 1 | digital | uint8 | 0 / 100 | 0 / 100 | % | mask array |
| **Future** `signals/body_position` | position | 1 | digital | uint8 | 0 / 5 | 0 / 5 | code | `categories` attr |

- **`storage="digital"`** (lossless int) is the case for **every captured channel**: the
  integer is stored exactly and EDF↔Zarr↔EDF is bit-identical throughout.
- **`storage="physical"`** (float32 calibrated) survives only in `derived/`, where Python
  processing writes real units (mg magnitudes, ms RMSSD). Ingest never emits it today.
- **`signals/rr` carries no information.** The channel is declared with transducer `"N/A"` and the
  firmware writes zeros — there is no R-peak detection on the device. Ingest must **not** silently
  present it as a valid series; mark it fully masked (`rr_mask` all-1) or set an explicit
  `no_source: true` attr so `compute_hrv` cannot be fed zeros and report a confident RMSSD. See
  [hardware](../knowledge/hardware.md).
- **`accel0_*`/`accel1_*` are int16 in mg, not uint16 ADC counts.** The MMA8451 reports signed
  physical acceleration, `digital_min/max = −8192/8191` against `±2000 mg` — see the §8 DSP-domain
  note.
- **24-bit EEG → int32** (sign-extended), with `bit_depth: 24` and `digital_min/max: −8388608/8388607` (the 24-bit range, **not** the int32 range — the C++ BDF exporter needs this to pack 3-byte two's-complement little-endian words). Never store raw 3-byte packed samples.
- **Dtype subset is the portable intersection only:** `{int16, int32, uint8, uint16, float32, float64}`. No `object`, structured/record, string, or `datetime64` dtypes anywhere (Python-only traps).

> **Two raw data-quality facts to escalate to Dmitry, not silently absorb.** (1) The RIP physical range is still ±1e6 nH against 16-bit digital — an EDF quantum of 2e6/65535 ≈ **30.5 nH per LSB**. The firmware now compensates on the *digital* side, dividing raw LDC1612 counts by per-channel constants (`THORACIC_DIVISOR 15`, `ABDOMEN_DIVISOR 11`, `logger.cpp:194–195`) so the swing occupies more of the digital range, but it does **not** adjust the declared physical range to match. Net effect: resolution is recovered, and the header's affine map no longer produces nanohenries. The divisors were tuned on **one night's** peak swing with ~2× headroom and can still saturate. Both halves belong in provenance. Tracked as open fork **O3**. (2) `logger.cpp` subtracts a baseline from thoracic/abdomen *before* writing (captured at `BASELINE_DELAY_S = 1200`, averaged over `BASELINE_AVG_SAMPLES = 50`), so the EDF "raw" is **already baseline-subtracted** — and, since 2026-07-19, that baseline may have been **restored from RTC memory across a reboot**, meaning it can predate the recording's own start time. The firmware's JSON sidecar records this in its `ldc_baseline` block (`ch0`/`ch1`/`valid`/`reused`/`reset_reason`/`delay_s`); ingest must fold it into `provenance.on_device_transforms` rather than let it stop at the device.

### 3.3 Per-array attribute convention

Attributes live in the array's `.zattrs` (plain JSON only — cast every numpy scalar to native `float`/`int` before writing). All keys required unless marked optional. Example `signals/thoracic/.zattrs`:

```json
{
  "protosom_role": "signal",
  "storage": "digital",
  "label": "Thoracic",
  "edf_label": "Thoracic",
  "transducer": "LDC1612 CH0",
  "edf_physical_dimension": "counts",
  "harmonized_unit": "counts",
  "kind": "respiratory_effort",
  "sample_rate_hz": 50.0,
  "edf_digital_min": -32767, "edf_digital_max": 32767,
  "edf_physical_min": -1000000.0, "edf_physical_max": 1000000.0,
  "edf_record_duration_s": 10.0,
  "gain": 30.518043793, "offset": 0.0,
  "on_device_divisor": 15,
  "t0_offset_s": 0.0,
  "n_samples": 1620000,
  "mask_array": "thoracic_mask",
  "source_device": "esp32c6",
  "source_edf_signal_index": 0,
  "_ARRAY_DIMENSIONS": ["time"]
}
```

| Key | Meaning / contract |
|---|---|
| `protosom_role` | `signal` \| `derived` \| `pyramid` \| `mask`. Lets readers/validators branch without path parsing. |
| `storage` | `physical` \| `digital` (§3.2). The single most important attr: tells every reader and the exporter whether the array holds calibrated floats or raw ints. |
| `edf_label`, `transducer`, `edf_physical_dimension` | **Verbatim EDF header strings** — guarantee EDFBrowser-identical labels on export. `edf_physical_dimension` is the literal byte string (e.g. `"Pressure"` for flow, `"ADC"` for ecg). |
| `harmonized_unit` | Post-hoc corrected unit (e.g. `mbar` for flow). Never replaces `edf_physical_dimension`; both are kept so an auditor sees the divergence is deliberate. |
| `kind` | Controlled vocab (§6.3) the viewer/DSP key off, not the free-text label. |
| `sample_rate_hz` | The only per-array clock. With `t0` (root) + `t0_offset_s` + index, every sample has an absolute time (§3.4). |
| `edf_digital_min/max`, `edf_physical_min/max` | Verbatim from EDF. Source of truth for calibration: `gain=(pmax−pmin)/(dmax−dmin)`, `offset=pmin−gain·dmin`, `physical=gain·digital+offset`. (Worked: thoracic gain = 2e6/65534 = 30.5180…; offset = 0.0. Note the span is 65534, not 65536 — `logger.cpp` declares a **symmetric** ±32767 digital range, not −32768/32767.) `gain`/`offset` are stored as convenience; recompute from min/max on export to avoid float drift. |
| `on_device_divisor` | *(RIP channels only, optional.)* The `THORACIC_DIVISOR`/`ABDOMEN_DIVISOR` the firmware applied to raw counts before writing. Informational — it is **not** part of the EDF affine map, and it is why `physical` on these two channels is not nanohenries. Recording it is what lets an auditor reconstruct the true count scale. |
| `edf_record_duration_s` | EDF data-record duration of the source (**10.0** — `RECORD_DURATION_S`, set via `edf_set_datarecord_duration` at `logger.cpp:469`). Independent of the Zarr chunk length, which is chosen purely for slicing. Note that EDF's `samplefrequency` field is samples-*per-record*, so effective Hz = `samplefrequency / edf_record_duration_s`; this is where the `RR` channel's fractional 2.5 Hz lives (25 samples/record). |
| `fill_value_meaning` / mask ref | Gap convention (§3.5). |
| `_ARRAY_DIMENSIONS` | xarray convention, plain JSON string array (C++-safe): `["time"]`, or `["channel","time"]` (EEG), or `["freq","time"]` (spectrogram). |

### 3.4 Time & alignment

- **One shared origin per recording**, `t0_iso` (root `.zattrs`), stored ISO-8601 with explicit offset. **It is the whole-second EDF header start.** `logger.cpp:502` sets only whole-second `edf_set_startdatetime`, so any subsecond fraction is *not* in the raw header. For the PoC, `t0_iso` is whole-second; any subsecond origin is tracked separately and emitted as the `+0.X` first time-keeping TAL on export (edflib supports this once firmware passes a fractional start — it does not today, so the raw subsecond origin is already lost; flag to Dmitry). The device's own JSON sidecar carries `recording_start_time` plus an explicit `timezone`, which is the better source for the ISO offset than inferring one.
- **No global time axis, no per-sample timestamp arrays** for uniform signals. Sample `i` → `t0 + t0_offset_s + i / sample_rate_hz`. Time is `int64` Unix-ns / ISO in attrs; never a `datetime64` dtype. **Irregular series (HRV) carry a `float64` `*_t` companion** in seconds-from-t0 (float64, not float32 — at 28800 s a float32 step is ~0.004 s, too coarse for beat timing).
- **One device, one clock — there is no cross-device alignment problem.** Every channel in a recording comes off the same ESP32-C6 timebase (serial time sync + a DS3231 RTC), so an event scored on one channel may freely reference any other. `source_device` and `t0_offset_s` are retained in the schema for forward-compatibility, but today `source_device` is uniformly `"esp32c6"` and `t0_offset_s` is uniformly `0.0`. The `offset_s + skew_ppm` model in §6.4 is a **single** device-to-UTC statement, not a device-to-device reconciliation. If a second acquisition device is ever added, the drift caveat comes with it and must be derived — a constant offset cannot correct skew over a night.

### 3.5 Gap / missing-data model

The signal-arrays slice's "fill_value = digital_min" scheme is broken against the actual firmware and is **dropped**. The firmware writes **0** on source failure, and `0` is a legal physiological/ADC value — so a real dropout is indistinguishable from a valid zero, and `digital_min` is in fact never written. The convention:

- **Every captured array is `storage="digital"` (int)**, so the gap mechanism is uniformly a companion **`uint8` mask array** (`<name>_mask`, `0`=valid, `1`=gap) — no in-band int sentinel is safe. Mask arrays carry `protosom_role: "mask"`.
- **`storage="physical"` (float32) arrays** exist only in `derived/`. There the gap sentinel is **`NaN`** (JSON string `"NaN"` in `.zattrs` fill_value — never a bare token; a C++ writer must emit the literal string).
- **`signals/rr` is a whole-array gap.** It is not "sometimes missing" — it has no source at all and is zeros end to end. Its mask should be all-1 from ingest, so downstream code that respects masks cannot mistake it for a flat-but-valid series.
- The `events.json` `gap` annotation (§5) is an optional human-readable index, never the sole record of a gap.

---

## 4. Decimation-pyramid convention

The viewer asks the server for `(channel, window, target_px)`; the server decides the level. This contract is unchanged whether the pyramid is precomputed or the server decimates l0 on the fly — so v0.1 ships on-the-fly decimation and a build step fills `pyramid/` later **with zero viewer change**.

- **min/max pairs, interleaved in one array**, shape `(n, 2)` last axis `[min, max]` (2D EEG: `[channel, n, 2]`). Min/max preserves spikes/apneas that mean-decimation would hide; interleaving (vs separate `_min`/`_max` arrays) halves file count and makes a pixel's min–max band one contiguous read. **No LTTB in v0.1.** Pyramid arrays inherit the base array's dtype/calibration and add `decimation_factor`, `parent`, `protosom_role: "pyramid"`.
- **Factor 4 per level** (`l1=÷4, l2=÷16, …`), giving ~log₄(N) levels. Stop when a level's length ≤ 4096 (read whole anyway).
- **Pyramid chunk length = `clamp(round(base_chunk_len / factor), 2048, base_chunk_len)`**; any level ≤ 8192 samples is a single chunk. This avoids the micro-chunk inode-waste the naive `base/factor` rule hits at coarse levels.
- **Server level selection (arithmetic, no metadata scan):** for window `[t0,t1]`, viewport width `W`, required samples ≈ `(t1−t0)·rate`; pick the smallest factor `f` with `(t1−t0)·rate / f ≤ 2·W`; read `pyramid/<ch>/<level(f)>` over the window, or `signals/<ch>` if `f==1`. Between levels the server decimates the *chosen coarser level* to `target_px` — O(level samples), not O(l0).
- **Gap-aware decimation (part of the build contract):** exclude NaN / masked samples from a bin's min/max; if a whole bin is gap, emit NaN so the renderer draws nothing — otherwise gaps render as full-scale spikes exactly where data is missing.

**Pyramid depth, worked (8-hour night):**

| Array | rate | l0 samples | levels (factor 4) | top level |
|---|---|---|---|---|
| `thoracic` | 50 | 1.44M | l1..l5 (÷4..÷1024) | ~1406 samples |
| `accel0_x` (×6 accel axes) | 50 | 1.44M | l1..l5 (÷4..÷1024) | ~1406 samples |
| `ecg` | 100 | 2.88M | l1..l6 (÷4..÷4096) | ~703 samples |
| `eeg` (256 Hz, time axis only) | 256 | 7.37M | l1..l6 (÷4..÷4096) | ~1800 samples |

Note the accel axes moved from 10 Hz to **50 Hz** with the MMA8451, and there are now **six** of
them rather than three — 5× the rate across 2× the channels is a **10× increase** in accelerometry
volume over the original estimate. It is still small next to the spectrogram, but it is no longer
negligible against `thoracic`/`ecg`.

**Spectrogram (largest future array, must be spec'd concretely):** 8 h @ nfft=512/hop=256 ≈ 1.8M frames × 257 bins × f32 ≈ **1.85 GB**. Chunk `[all_freq=257, time_chunk≈512]` (~526 KB/chunk, in the ~1 MB sweet spot — **not** the 120 s rule, which would give 7.7 MB chunks). It gets its own **time-axis max/mean pyramid** like EEG so a whole-night overview is not a 1.85 GB scan. Put the decode budget in view: at ~5–10 GB/s Blosc-zstd a full-night scan is ~0.2–0.4 s, hence the overview must hit the pyramid, not l0.

---

## 5. Events / annotations JSON sidecar

**Rule:** dense & regularly-sampled → Zarr; sparse, ragged, or typed-with-provenance → `events.json`. JSON Schema **Draft 2020-12**, validatable from Python (`jsonschema`) and C++ (`nlohmann/json` + `pboettch/json-schema-validator`). No NaN/Inf (forbidden in JSON — use `null`); `onset_s`/`duration_s` are `double`.

**Key model decisions:** one general Event model (`onset_s, duration_s, type, channels, params, confidence`) covers LM, apnea, hypopnea, RERA, arousal, desaturation, **and** each 30-s hypnogram epoch (a stage is an event whose `duration_s` == epoch length). PLM series are a **Group** referencing member LM events by `id` (not nested `[[onset,offset]]` pairs — that shape is lossy). Multiple scorers coexist as `scorings[]` entries in one file. HRV is **not** here — it is a dense Zarr array (§3); only its overall scalar lives in `meta.json` stats. Time-base is `float64` seconds from `recording_start`, matching the EDF+ TAL onset convention so `onset_s` maps 1:1 to the export `+onset` field. **`event.channels[]` and `group`/`event` channel references use the canonical snake_case Zarr array names from §3.2** (e.g. `ecg`, `accel0_mag`, `accel_combined_mag`, future `eeg`), never EDF+ labels.

### 5.1 Schema (abridged to the load-bearing `$defs`)

```jsonc
{
  "$schema": "https://json-schema.org/draft/2020-12/schema",
  "$id": "protosom/events-1.0.0.json",
  "type": "object",
  "required": ["schema", "schema_version", "recording_id", "time_base", "scorings"],
  "properties": {
    "schema":         { "const": "protosom.events" },
    "schema_version": { "type": "string", "pattern": "^\\d+\\.\\d+\\.\\d+$" },
    "recording_id":   { "type": "string" },
    "time_base": {
      "type": "object", "required": ["reference","start_iso","unit"],
      "properties": {
        "reference": { "const": "recording_start" },
        "start_iso": { "type": "string", "format": "date-time" },  // == meta.json + Zarr t0 (whole-second)
        "unit":      { "const": "s" }
      }
    },
    "channels_ref": { "const": "working.zarr" },
    "scorings":     { "type": "array", "items": { "$ref": "#/$defs/scoring" } }
  },
  "$defs": {
    "scoring": {
      "type": "object",
      "required": ["scoring_id","scorer","scoring_method","provenance","events"],
      "properties": {
        "scoring_id":     { "type": "string" },
        "scorer":         { "type": "object", "required": ["kind","name"],
                            "properties": { "kind": {"enum":["human","algorithm"]},
                                            "name": {"type":"string"}, "version": {"type":"string"} } },
        "scoring_method": { "enum": ["auto","manual","hybrid"] },
        "hypopnea_rule":  { "enum": ["1A","1B"] },     // required when any hypopnea present
        "provenance":     { "$ref": "#/$defs/provenance" },
        "events":         { "type": "array", "items": { "$ref": "#/$defs/event" } },
        "groups":         { "type": "array", "items": { "$ref": "#/$defs/group" } }
      }
    },
    "event": {
      "type": "object",
      "required": ["id","type","onset_s","duration_s"],
      "properties": {
        "id":         { "type": "string" },           // unique within this scoring
        "type":       { "type": "string" },           // controlled vocab §5.2
        "onset_s":    { "type": "number", "minimum": 0 },
        "duration_s": { "type": "number", "minimum": 0 },
        "channels":   { "type": "array", "items": { "type": "string" } },  // canonical Zarr names
        "confidence": { "type": "number", "minimum": 0, "maximum": 1 },
        "respiratory_associated": { "type": "boolean" },  // LM excluded from PLMI per AASM if true
        "links":      { "type": "array", "items": {        // typed cross-event refs (hypopnea→arousal)
                          "type": "object", "required": ["rel","target_id"],
                          "properties": { "rel": {"type":"string"}, "target_id": {"type":"string"} } } },
        "params":     { "type": "object" }
      }
    },
    "group": {
      "type": "object",
      "required": ["id","type","member_ids"],
      "properties": {
        "id": {"type":"string"}, "type": {"type":"string"},
        "member_ids": { "type": "array", "items": {"type":"string"} },
        "onset_s": {"type":"number"}, "duration_s": {"type":"number"}, "params": {"type":"object"}
      }
    },
    "provenance": {
      "type": "object",
      "required": ["function","code_version","params","input_signals","raw_refs"],
      "properties": {
        "function":      { "type": "string" },
        "code_version":  { "type": "string" },     // full 40-char git SHA + ":dirty" suffix if dirty
        "params":        { "type": "object" },
        "source_constants": { "type": "object" },  // hardcoded constants, informational (see note)
        "input_signals": { "type": "array", "items": {"type":"string"} },
        "raw_refs":      { "type": "array", "items": {   // list, because a recording can have >1 raw EDF
                             "type": "object", "required": ["path","hash"],
                             "properties": { "path": {"type":"string"}, "hash": {"$ref":"#/$defs/hash"} } } }
      }
    }
  }
}
```

### 5.2 Controlled vocabulary (`type`)

| `type` | duration | scored on (canonical names) | notes |
|---|---|---|---|
| `limb_movement` | 0.5–10 s | `accel0_mag`, `accel1_mag`, `accel_combined_mag` | `respiratory_associated:true` ⇒ excluded from PLMI ([AASM](https://aasm.org/)) |
| `apnea_obstructive` / `_central` / `_mixed` | ≥10 s, ≥90% flow drop | `flow`,`thoracic`,`abdomen` | effort distinguishes subtype |
| `hypopnea` | ≥10 s, ≥30% flow drop + (desat or arousal) | `flow`,`spo2` | scoring `hypopnea_rule` 1A/1B required; `params.subtype: obstructive\|central` optional |
| `rera` | ≥10 s effort/flattening → arousal | `flow`,`eeg` | |
| `arousal` | ≥3 s EEG shift | `eeg`,`emg` | |
| `desaturation` | local ≥3% SpO2 drop | `spo2` | `params.nadir_pct`,`drop_pct` |
| `sleep_stage` | epoch (30 s) | `eeg`,`eog`,`emg` | `params.stage` ∈ `[W,N1,N2,N3,R,movement,unscored,artifact]` |
| `gap` | dropout span | the affected channel | optional human index of a §3.5 gap |

**Hypnogram invariant (validator-enforced):** `sleep_stage` events within one scoring tile `[lights_off_s, lights_on_s]` contiguously at `epoch_s`, no gaps/overlaps; `movement`/`unscored`/`artifact` are explicit (EDF+ `?` / `Movement time`). The scoring carries `lights_off_s`/`lights_on_s` so TST and sleep efficiency are computable.

### 5.3 TODAY example (LM/PLM; HRV deliberately absent)

```jsonc
{
  "schema": "protosom.events", "schema_version": "1.0.0",
  "recording_id": "2026-07-16_2300_protosom-c6",
  "time_base": { "reference": "recording_start", "start_iso": "2026-06-19T22:14:03", "unit": "s" },
  "channels_ref": "working.zarr",
  "scorings": [{
    "scoring_id": "plm-auto-v0",
    "scorer": { "kind": "algorithm", "name": "protosom.count_plm", "version": "0.3.1" },
    "scoring_method": "auto",
    "provenance": {
      "function": "signal_processing.count_plm",
      "code_version": "81955d3...e (full SHA)",
      "params": { "threshold": 8.0, "fs": 50, "max_threshold": 500.0, "tilt_threshold_deg": 10.0,
                  "window_sec": 30 },
      "source_constants": { "lm_min_dur_s": 0.5, "lm_max_dur_s": 10.0,
                            "plm_min_gap_s": 5, "plm_max_gap_s": 90, "plm_min_series": 4,
                            "min_gravity_mg": 100 },
      "input_signals": ["accel_combined_mag"],
      "raw_refs": [{ "path": "raw/biometric_2026-07-16_23-00-00.edf",
                     "hash": { "algorithm": "blake3", "value": "af3c…91" } }]
    },
    "events": [
      { "id":"ev_0001","type":"limb_movement","onset_s":1432.5,"duration_s":1.3,"channels":["accel_combined_mag"],"params":{"peak_vm":14.2} },
      { "id":"ev_0002","type":"limb_movement","onset_s":1454.9,"duration_s":0.9,"channels":["accel_combined_mag"],"params":{"peak_vm":11.0} },
      { "id":"ev_0003","type":"limb_movement","onset_s":1478.1,"duration_s":1.1,"channels":["accel_combined_mag"],"params":{"peak_vm":12.7} },
      { "id":"ev_0004","type":"limb_movement","onset_s":1500.4,"duration_s":1.0,"channels":["accel_combined_mag"],"params":{"peak_vm":13.1} }
    ],
    "groups": [
      { "id":"grp_plm_001","type":"plm_series","member_ids":["ev_0001","ev_0002","ev_0003","ev_0004"],
        "onset_s":1432.5,"duration_s":69.0,"params":{"n_movements":4,"mean_interval_s":22.6} }
    ]
  }]
}
```

> `peak_vm`, `n_movements`, `mean_interval_s`, and per-LM `id`s are **NOT produced by today's `count_plm`** (it emits anonymous `(on/fs, off/fs)` second-tuples). The migrator must assign deterministic ids before `member_ids` can reference them; the params are NEW fields requiring a `count_plm` extension, optional/absent in plain migration. `threshold:8` is on the **retired uint8 byte-log scale** and has never been recalibrated for the MMA8451's mg output — as are `max_threshold` and `tilt_threshold_deg`, tuned against a single recording. All three are uncalibrated placeholders; see the §8 note and open fork **O12** in [decisions](../state/decisions.md). Note there are now **three** scorings per recording (per-leg Accel0, per-leg Accel1, and the bilateral combined headline), not one.

### 5.4 FUTURE example (apnea + hypopnogram, two scorers)

```jsonc
{
  "schema": "protosom.events", "schema_version": "1.0.0",
  "recording_id": "2027-03-02_2300_protosom-full",
  "time_base": { "reference": "recording_start", "start_iso": "2027-03-02T23:00:00", "unit": "s" },
  "channels_ref": "working.zarr",
  "scorings": [
    {
      "scoring_id": "resp-auto-v1",
      "scorer": { "kind": "algorithm", "name": "protosom.detect_resp", "version": "1.2.0" },
      "scoring_method": "auto", "hypopnea_rule": "1A",
      "provenance": { "function": "signal_processing.detect_respiratory_events",
        "code_version": "deadbeef…(full)", "params": { "apnea_drop_pct": 90, "hypopnea_drop_pct": 30, "min_dur_s": 10, "desat_pct": 3 },
        "input_signals": ["flow","thoracic","abdomen","spo2"],
        "raw_refs": [{ "path":"raw/biosignals.bdf", "hash": {"algorithm":"blake3","value":"ffe…"} }] },
      "events": [
        { "id":"ev_a01","type":"apnea_obstructive","onset_s":4210.0,"duration_s":18.4,
          "channels":["flow","thoracic","abdomen"],"params":{"flow_drop_pct":96,"paradoxical":true},"confidence":0.88 },
        { "id":"ev_h01","type":"hypopnea","onset_s":4905.2,"duration_s":14.0,"channels":["flow","spo2"],
          "params":{"flow_drop_pct":42,"desat_pct":4.1,"subtype":"obstructive"},
          "links":[{"rel":"caused_arousal","target_id":"ev_ar01"}],"confidence":0.74 },
        { "id":"ev_d01","type":"desaturation","onset_s":4912.0,"duration_s":22.0,"channels":["spo2"],"params":{"nadir_pct":89.5,"drop_pct":4.1} },
        { "id":"ev_ar01","type":"arousal","onset_s":4923.0,"duration_s":4.2,"channels":["eeg"] }
      ]
    },
    {
      "scoring_id": "hypnogram-auto-v1",
      "scorer": { "kind": "algorithm", "name": "protosom.stage_sleep", "version": "1.0.0" },
      "scoring_method": "auto", "lights_off_s": 0.0, "lights_on_s": 28800.0,
      "provenance": { "function": "signal_processing.stage_sleep", "code_version": "deadbeef…(full)",
        "params": { "epoch_s": 30, "model": "yasa-like-v1" },
        "input_signals": ["eeg","eog","emg"], "raw_refs": [{ "path":"raw/biosignals.bdf", "hash": {"algorithm":"blake3","value":"ffe…"} }] },
      "events": [
        { "id":"ep_0001","type":"sleep_stage","onset_s":0.0,  "duration_s":30.0,"params":{"stage":"W"} },
        { "id":"ep_0002","type":"sleep_stage","onset_s":30.0, "duration_s":30.0,"params":{"stage":"N1"} },
        { "id":"ep_0003","type":"sleep_stage","onset_s":60.0, "duration_s":30.0,"params":{"stage":"N2"} },
        { "id":"ep_0004","type":"sleep_stage","onset_s":90.0, "duration_s":30.0,"params":{"stage":"N3"} }
        /* … one per 30-s epoch for the whole night (~960 events; fine as JSON) … */
      ]
    }
  ]
}
```

---

## 6. Metadata + provenance + 3-layer manifest (`meta.json`)

Metadata lives in a standalone `meta.json` at the recording root, **not** in Zarr `.zattrs` — it is C++-readable with zero Zarr dependency and must describe layers (raw EDF+/FLAC) that exist outside Zarr. The Zarr root `.zattrs` carries only a back-pointer. JSON Schema Draft 2020-12.

### 6.1 Root `.zattrs` (back-pointer only)

```json
{ "protosom_meta": "meta.json", "protosom_schema_version": "0.1.0",
  "recording_id": "2026-07-16_2300_protosom-c6", "t0_iso": "2026-06-19T22:14:03+01:00" }
```

### 6.2 `meta.json` structure & version manifest

```jsonc
{
  "schema_versions": { "meta": "0.1.0", "events": "1.0.0", "zarr_arrays": "0.1.0" },  // the one triple
  "recording_id": "2026-07-16_2300_protosom-c6",
  "subject":    { /* §6.3 */ }, "recording": { /* start/duration/site */ },
  "device":     { /* §6.3 channel registry — SOLE source of truth for channel names */ },
  "layers":     { /* §6.4 manifest */ }, "provenance": { /* §6.5 */ },
  "stats":      { /* study-level indices — the ONE home: AHI, ODI, arousal_index,
                     plmi, plmi_with_arousal, tst_s, sleep_efficiency, hrv_rmssd_overall */ }
}
```

A single semver format everywhere (`0.1.0`, not `0.1`). Readers check the major version of each axis and refuse mismatches. Study-level summary indices have exactly one home (`meta.json.stats`); `events.json` and `_meta.json` are no longer summary homes. **AHI** (the headline PSG number) and ODI/arousal index/sleep efficiency/TST are named optional fields here, computed from events + hypnogram.

### 6.3 `subject` + `device` (channel registry)

`subject` splits a de-identified core (always present, committable) from an optional `pii` block:

```json
"subject": { "subject_id": "PSG-0001", "sex": "male", "dob": "1990-01-01",
             "age_years_at_recording": 36,
             "pii": { "name": "…", "nhs_number": "9999999999", "email": "…" } }
```

`device.channels[]` is the **single canonical channel-name registry** every other slice references: each entry binds `{label (verbatim EDF), zarr_array (canonical snake_case), kind, transducer, fs_hz, storage, dtype, edf_physical_dimension, harmonized_unit, digital_min/max, physical_min/max, raw_edf_signal_index}` per §3.2/§3.3. `kind` controlled vocab: `respiratory_effort | airflow_pressure | airflow_thermal | ecg | heart_rate | rr_interval | spo2 | eeg | eog | emg | accelerometer | body_position | audio_derived | snore`.

### 6.4 `layers` — 3-layer manifest (hashing + audio anchor + per-device clock)

```jsonc
"layers": {
  "raw": {
    "biosignals": [                                  // LIST — kept a list for forward-compat,
      { "path": "raw/biometric_2026-07-16_23-00-00.edf",      // but single-device = one entry
        "format": "EDF+", "signals": 11,
        "hash": { "algorithm": "blake3", "value": "af3c…91" }, "bytes": 84672000,
        "header_start_datetime": "2026-07-16T23:00:00",       // whole-second
        "record_duration_s": 10.0,
        "device": "esp32c6",
        "device_sidecar": { "path": "raw/biometric_2026-07-16_23-00-00.json",
                            "hash": { "algorithm": "blake3", "value": "3d81…7f" } },
        "clock": { "offset_to_utc_s": 0.0, "skew_ppm": null, "source": "serial_sync+ds3231",
                   "discipline": "manual_serial", "uncertainty_s": 1.0 } }
    ],
    "audio": {
      "path": "raw/snore_16k.flac", "format": "FLAC",
      "hash": { "algorithm": "blake3", "value": "7b21…0e" }, "bytes": 921600000,
      "sample_rate_hz": 16000, "channels": 1,
      "time_anchor": { "audio_t0_offset_s": 12.734, "reference": "recording.start_datetime",
                       "method": "manual", "offset_uncertainty_s": 0.5,
                       "note": "FLAC sample 0 occurs 12.734 s AFTER t0. Positive = audio starts later." }
    }
  },
  "working": {
    "path": "working.zarr", "zarr_format": 2, "dimension_separator": ".",
    "store_hash": { "algorithm": "blake3", "value": "c4d9…aa",
                    "method": "blake3-of-sorted-(relpath\\tblake3)-list", "purpose": "integrity_only" },
    "value_digests": { "signals/thoracic": { "algorithm": "blake3",
                       "value": "…", "method": "blake3-of-decoded-LE-sample-buffer" } },  // §9 re-derivation check
    "events_sidecar": { "path": "events.json", "hash": { "algorithm": "blake3", "value": "1f0a…3c" } }
  },
  "export": {
    "clinical": { "path": "export/clinical.edf", "format": "EDF+", "deidentified": true,
                  "generated_from": "working.zarr",
                  "hash": { "algorithm": "blake3", "value": "dd54…b2" }, "bytes": 84680000 }
  }
}
```

- **Hashing: BLAKE3**, recorded as `{algorithm, value}` so a per-hash switch to `sha256` needs no schema change. ~3× SHA-256 throughput, important for the multi-GB EEG/audio envelope.
- **Zarr has no single file to hash**, so `store_hash` is a Merkle digest over the sorted `(relpath, blake3-of-file)` list. **It is integrity-only** (compressed bytes are not reproducible across lib/codec versions). Re-derivation correctness is checked against the separate **`value_digests`** — BLAKE3 over each array's decoded little-endian sample buffer, codec/chunk-independent (see §9).
- **Audio time-anchor** maps a playhead: `signal_t = audio_sample/16000 + audio_t0_offset_s`. `method` ∈ `ntp_aligned | clap_sync | manual | unknown` records *how* it was established + `offset_uncertainty_s`, so trustworthiness is auditable. A hand-entered value is `method:"manual"` with explicit uncertainty.
- **`clock`** carries `offset_to_utc_s`, `skew_ppm`, `source`, `discipline`, `uncertainty_s` — a linear model, because a constant offset is wrong by seconds over an 8 h night at ~50 ppm drift. With one device this describes **device-to-UTC** only; there is no longer a second clock to reconcile against. The ESP32-C6 is disciplined by manual serial sync against a DS3231 RTC (no NTP — the radios are off by design), so `uncertainty_s` is bounded by how carefully `tools/set_time.py` was last run, and `skew_ppm` is unmeasured. Measuring the DS3231's actual skew across a night is the cheapest available accuracy win.
- **`device_sidecar`** references the JSON the firmware itself writes next to the EDF+ (`device_uid`, timezone, sensor presence/rates, `ldc_baseline`). It is part of layer 1 and must be hashed alongside the EDF+ — it is the only record of the on-device baseline transform, and without it §6.5's `on_device_transforms` cannot be populated truthfully.

### 6.5 `provenance` — IEC-62304 reproducibility

```jsonc
"provenance": {
  "generated_at": "2026-06-20T09:00:00Z",
  "pipeline": { "repo": "sunrise-designs/ProtoSom",
                "git": { "sha": "9f2a…(full 40)", "dirty": false, "branch": "main", "describe": "v0.1.0-3-g9f2a7c1" } },
  "firmware": { "git_sha": null, "dirty": null, "equipment_string": null,
                "note": "NOT AVAILABLE — the C6 firmware sets no equipment string and compiles in no git hash. See §6.5 note." },
  "input_preparation": { "skip_samples": 700, "ignore_last_samples": 0,
                         "note": "leading 14 s dropped before DSP at 50 Hz; shifts every onset and the PLMI denominator" },
  "on_device_transforms": [ { "name": "rip_baseline_subtraction",
                              "note": "baseline captured 20 min in, averaged over 1 s, subtracted from thoracic/abdomen before EDF write; MAY be restored from RTC across a reboot",
                              "params": { "baseline_delay_s": 1200, "baseline_avg_samples": 50 },
                              "from_device_sidecar": { "ch0": 123456, "ch1": 234567, "valid": true,
                                                       "reused": false, "reset_reason": 1 } },
                            { "name": "rip_count_division",
                              "note": "raw LDC1612 counts divided per-channel before EDF write; declared physical range NOT adjusted to match, so header physical units are not nH",
                              "params": { "thoracic_divisor": 15, "abdomen_divisor": 11 } } ],
  "environment": {
    "os": "Windows 11 26200", "host_arch": "x86_64",          // re-derivation host arch matters for float determinism
    "python": { "version": "3.11.2", "lockfile": "src_python/requirements.lock",
                "lockfile_hash": { "algorithm": "blake3", "value": "5e9b…d7" } },
    "key_packages": { "numpy": "1.26.4", "scipy": "1.13.0", "zarr": "2.18.2" },
    "cpp_toolchain": { "compiler": "g++ 12.2.0", "libs": { "edflib": "1.21" } } },
  "derived_products": [
    { "product": "derived/accel0_mag", "code_ref": "signal_processing.py::accel_magnitude",
      "git_sha": "9f2a…(full)", "source_arrays": ["signals/accel0_x","accel0_y","accel0_z"],
      "params": { "window_sec": 30, "fs": 50 },
      "value_digest": { "algorithm": "blake3", "value": "…" } },
    { "product": "derived/accel_combined_mag", "code_ref": "signal_processing.py::combine_bilateral_vm",
      "git_sha": "9f2a…(full)", "source_arrays": ["derived/accel0_mag","derived/accel1_mag"],
      "params": { "threshold": 8.0, "fs": 50, "max_threshold": 500.0 },
      "value_digest": { "algorithm": "blake3", "value": "…" } },
    { "product": "events.json#plm-auto-v0", "code_ref": "signal_processing.py::count_plm",
      "git_sha": "9f2a…(full)", "source_arrays": ["derived/accel_combined_mag"],
      "params": { "threshold": 8.0, "fs": 50, "max_threshold": 500.0, "tilt_threshold_deg": 10.0,
                  "window_sec": 30 },
      "source_constants": { "lm_dur_s": [0.5,10.0], "plm_gap_s": [5,90], "plm_min_series": 4,
                            "min_gravity_mg": 100 } },
    { "product": "derived/hrv_rmssd", "code_ref": "signal_processing.py::compute_hrv",
      "git_sha": "9f2a…(full)", "source_arrays": ["signals/rr"],
      "params": { "window_sec": 300, "fs": 2.5, "rr_valid_ms": [300,2000] },
      "note": "signals/rr has NO SOURCE on this hardware — it logs zeros. Any RMSSD derived from it is meaningless and must not be emitted as a stat until R-peak detection exists.",
      "value_digest": { "algorithm": "blake3", "value": "…" } }
  ]
}
```

**Three provenance fixes the reviewers forced:**

1. **Hardcoded constants are `source_constants`, not `params`.** The AASM constants in `count_plm` (lines 45–55) are source literals, not function arguments. Presenting them as re-derivation knobs is provenance theatre — restoring them from JSON and re-running gets the source-baked values regardless. They are recorded as informational `source_constants`; the **`git_sha` + `code_ref` is their authoritative capture.** A CI assertion checks every key in `params` corresponds to a real named function argument.

2. **`window_sec` is captured at the call site, not from argparse.** `count_plm` calls `remove_baseline(data, fs=fs)` **without** `window_sec` (line 29), so PLM detection always uses the 30 s default no matter what `--window` was set — recording the argparse value would lie. (Recommend fixing the code to thread `window_sec` through; until then, capture the effective value.)

3. **`input_preparation` and `on_device_transforms` are recorded.** `--skip` (default 700 = first 70 s dropped) and the on-device RIP baseline subtraction both mutate the signal upstream of any current provenance and were captured nowhere.

`git.sha` is the **full 40-char SHA + explicit `dirty` flag** for the *pipeline*. **Firmware provenance is absent.** The ESP32-C6 firmware sets **no equipment string at all** and compiles in **no git hash** — there is no `edf_set_equipment` call and no `GIT_COMMIT_HASH` anywhere in `ESP32-C6-heart-idf`. Every EDF+ this hardware produces is therefore **not audit-grade** by this spec's own standard. The fix: emit full SHA + dirty flag as a compile definition and write it at recording start (the 80-char equipment field is tight, so an annotation TAL is the likelier carrier). Until then, `provenance.firmware` must be explicitly `null` with a note — never silently omitted, which would read as "not applicable" rather than "missing".

---

## 7. EDF/BDF round-trip mapping & lossless guarantee

`ingest: EdfModel → ZarrModel` and `export: (ZarrModel, channel_selection, events) → EdfModel` are pure transforms; edflib (C++) / `pyedflib`/`edfio` (Python) are the only impure boundary.

EDF calibration: `physical = (digital − dmin)·(pmax − pmin)/(dmax − dmin) + pmin`.

| EDF label | rate | `storage` | Zarr array / dtype | export format | lossless? |
|---|---|---|---|---|---|
| Thoracic / Abdomen | 50 | digital | `signals/thoracic`,`abdomen` int16 | EDF+ | **bit-exact** |
| Flow | 50 | digital | `signals/flow` int16 | EDF+ | **bit-exact** |
| ECG | 100 | digital | `signals/ecg` int16 | EDF+ | **bit-exact** (phys range == digital range = identity today; guarded by test #4) |
| Accel0X/Y/Z, Accel1X/Y/Z | 50 | digital | `signals/accel{0,1}_{x,y,z}` int16 | EDF+ | **bit-exact**; phys ±2000 mg calibration preserved |
| RR | 2.5 | digital | `signals/rr` int16 | EDF+ | **bit-exact** (of zeros — the channel has no source) |
| EEG ×N (future) | 256 | digital | `signals/eeg` int32 (bit_depth 24) | **BDF+** | bit-exact, 3-byte two's-complement LE packing |

**What is lossless, precisely:** `digital(EDF_in) == digital(EDF_out)` sample-for-sample for **every** channel — exact **by construction for all eleven**, since the firmware writes digital samples and ingest stores the integer unchanged. The half-an-EDF-quantum caveat applies only to `storage="physical"` arrays, i.e. hypothetical future producers that write physical doubles.

**What is still lost, and it is upstream of everything here:** the RIP channels' on-device count division (`÷15`, `÷11`) is applied *before* the EDF write, so the pre-division raw LDC1612 counts are gone from the raw anchor permanently. The round-trip faithfully reproduces the divided values; it cannot recover what was divided away. Recording the divisors in provenance (§6.5) is what makes the transform *auditable*, not reversible.

**Format rule:** a file is uniformly EDF+ (2-byte) **or** BDF+ (3-byte); widths cannot mix. **Promote the whole export file to BDF+ if any selected channel has `digital_max > 32767` or `digital_min < −32768`** (i.e. 24-bit EEG). A full future montage forces all 16-bit channels to 3-byte too (~50% size inflation on those) — a stated, accepted cost; EDFBrowser reads such mixed-origin BDF correctly.

**Record-duration solver:** EDF needs `samples_per_record = rate × D` integral for every channel simultaneously. Pick the smallest `D` (LCM-of-denominators) per file. The current channel set is {50, 100, 2.5}: `D = 1 s` fails, because 2.5 Hz × 1 s = 2.5 samples — **`D` must be even-numbered in halves**, so the smallest valid `D` is **2 s** (RR → 5 samples/record). The firmware sidesteps this by using `D = 10 s` (RR → 25 samples/record), which is why `lround` is needed at `logger.cpp:494`. An exporter that naively defaults to `D = 1 s` will silently truncate the RR channel's rate to 2 Hz. A future 0.1 Hz body-position channel forces `D ≥ 10 s`. Zarr chunk length is independent of `D`.

**Events → EDF+ TAL (explicitly lossy):** each event `{onset_s, duration_s, label}` → one TAL `+<onset>\x15<duration>\x14<label>\x14\x00` (onset/duration ASCII decimal seconds from file start; the first TAL per record is the empty time-keeper `+<rec_start>\x14\x14\x00`). The rich model (type/channels/params/confidence/scoring_id) **collapses to one label string** — `events.json` is authoritative; EDF+ is a clinical-interop view. Label convention: `"OA"`, `"Hypopnea (1A)"`, `"Sleep stage N2"`, `"LM"`/`"PLM"`. **One EDF+ export per scoring** (multiple scorers cannot share one annotation stream unambiguously). onset/duration printed to 3 decimals (ms) — the documented re-parse tolerance. UTF-8 labels allowed; no `0x14`/`0x15` byte may appear in label text.

---

## 8. Language-neutrality — the C++-safe subset

**One-line contract for Dmitry:** *Zarr v2, C-order, little-endian fixed-width numeric dtypes from `{int16,int32,uint8,uint16,float32,float64}`, Blosc(zstd,shuffle) (or gzip/raw) compressor, `filters: null`, no string/object/datetime dtypes, `.zattrs` plain JSON, `dimension_separator: "."`.* Everything inside this subset round-trips identically through z5, TensorStore, xtensor-zarr, and zarr-python.

| Trap | Rule |
|---|---|
| `object`/structured dtypes (pickled) | Forbidden. Numeric fixed-width only. |
| numpy scalars/arrays in `.zattrs` | Cast to native `float`/`int`/list before writing; `.zattrs` is plain JSON. |
| string/`|S`/`|U`/VLen-UTF8 arrays | No string Zarr arrays. Categorical → `uint8` codes + `categories: [...]` attr; free text → JSON sidecar. |
| `datetime64`/`timedelta64` | No datetime dtype. Time is `int64` ns / ISO in attrs; irregular series use a `float64 *_t` companion. |
| numcodecs filters (Delta, FixedScaleOffset, PackBits, Categorize, Quantize) | `filters: null` everywhere. Byte-shuffle gives the delta benefit portably. |
| `.npy`/pickle/Pickle/MsgPack/JSON codecs | Forbidden. Chunk encoding is Blosc/zstd or gzip/raw only. |
| float fill_value | The JSON **string** `"NaN"` (and `"Infinity"`/`"-Infinity"`), never a bare token — a C++ writer (`nlohmann/json`) must emit the literal string, not `std::nan`. Integer arrays use a mask array, not in-band fill. |
| v2-vs-v3 `shuffle` encoding | v2 `.zarray` `shuffle` is the **integer** `1`/`2`; never copy a v3 string `"shuffle"` into a v2 store. |

**The DSP-domain trap (escalated, not buried):** `signals/accel0_x` holds the **int16 digital** sample in this store (−8192…8191), while the current DSP reads physical **mg** floats straight from the EDF+ via `edfio` and computes `vm` and the `threshold=8` LM cutoff in that mg space. The two differ by the header's affine map — a factor of ~0.244 mg/LSB. Adopting this schema **requires** refactoring the DSP to read `signals/accel{0,1}_{x,y,z}` from Zarr **and** either applying the calibration on read or recalibrating `threshold`, `max_threshold`, and the GPC gate's `MIN_GRAVITY_MG` into digital space — otherwise LM/PLM detection silently changes.

The safer refactor is to **apply the affine map on read** and keep the DSP entirely in mg, since every tuned constant (`threshold=8`, `max_threshold=500`, `tilt_threshold_deg=10`, `MIN_GRAVITY_MG=100`) is expressed in mg or degrees and none has been validated against a corpus (open fork **O12**). Changing the units *and* the thresholds in one step would make a detection regression indistinguishable from a units bug.

---

## 9. Property / round-trip tests (the IEC-62304 assertions)

Each is a mechanically-checkable pass/fail; the **equality criterion is defined per storage mode** so "reproduced correctly" is unambiguous.

1. **Digital exactness (headline):** for every channel, `digital(export(ingest(edf))) == digital(edf)` sample-for-sample. Exact for `storage="digital"`; holds for `storage="physical"` because calibration constants are reused. Property test over randomly generated EDF headers + buffers.
2. **Physical tolerance:** `storage="physical"` physical values equal within **±0.5 EDF quantum**. Derived float arrays: `rtol=1e-6, atol` documented per array.
3. **Header fidelity:** label, transducer, `edf_physical_dimension` (verbatim), sample rate, digital/physical min-max, start datetime, record duration survive `EDF → Zarr(attrs) → EDF`.
4. **ECG identity guard:** assert `digital_min/max = 0/4095` for `ecg` and that the phys-range==digital-range identity round-trips exactly — fails loudly if a future firmware change breaks it.
4b. **Fractional-rate guard:** assert the RR channel survives at **2.5 Hz** — that the record-duration solver never picks a `D` making `rate × D` non-integral, and that a 2.5 Hz channel round-trips without silently becoming 2 Hz. This is the `lround` bug at `logger.cpp:494` reappearing on the export side.
5. **BDF promotion:** any channel outside 16-bit ⇒ BDF+; a known ±8388607 vector round-trips exactly through 3-byte two's-complement LE packing.
6. **Annotation round-trip:** `{onset,duration,label}` → TAL bytes → re-parsed event equals original (onset/duration to ms; label byte-identical; no `0x14`/`0x15` in text).
7. **Record-duration solver:** chosen `D` makes `D×rate` integral for all channels; regression cases {50,1,5,100}, {10,1}, {0.1,1}.
8. **Cross-language conformance (CI gate):** one fixture recording written by zarr-python **and** by the chosen C++ lib produces byte-identical chunk files and `.zarray`/`.zattrs` (modulo Blosc version string) — proves the §8 subset is real. The fixture pins exact dtype/codec/shuffle-integer/`dimension_separator` so it would catch a v3-string-shuffle or a wrong fill encoding.
9. **Re-derivation value check:** re-running a derived product (e.g. `count_plm` at the recorded `git_sha` + lockfile on the hash-verified raw) reproduces events — exact integer match where the detection is integer-domain; for float-domain detection, value-equality within the §9.2 tolerance with `numpy`/`scipy`/arch pinned (float DSP is not bit-stable across BLAS/arch, which can flip `≥8` boundary cases). The `value_digests` (§6.4) make this a single comparable digest per array, independent of Zarr lib/chunking.

---

## 10. Open questions for Leon & Dmitry

1. **Vendor TensorStore, or stay on z5/xtensor-zarr?** v2 is chosen precisely to keep z5/xtensor-zarr open. If Dmitry commits to TensorStore (and explicitly drops z5), the v2-vs-v3 trade reopens and sharding becomes available — worth deciding before the high-res EEG envelope lands. *(This is the single biggest external dependency.)*
2. **Fix the RIP physical range, or bless the divisor workaround?** The firmware now recovers effective resolution by dividing raw counts (`÷15`, `÷11`) while leaving the declared ±1e6 nH range untouched — so the header lies about units. Three options: (a) tighten `physical_min/max` to match the divided scale and keep the divisors; (b) drop the divisors and tighten the range instead, which is the honest fix; (c) keep both and document the offset permanently. The divisors were tuned on **one night** with ~2× headroom and can still clip on deeper breathing, which argues against leaning on them. This remains the biggest data-quality lever in the pipeline. See open fork **O3**.
3. **PII anchor policy — largely resolved by the hardware change.** The C6 firmware writes **no** patient name or DOB into the EDF+ header (no `edf_set_patientname`/`edf_set_birthdate` calls exist), so the raw anchor is PII-free by construction and the old conflict — "the immutable hashed anchor embeds a name and cannot be scrubbed without changing its hash" — is **gone**. What remains to decide is narrower: whether `meta.json`'s `subject.pii` block ships alongside a shared working store or is stripped at share time, and whether `.gitignore` needs a `!meta.json` exception so a de-identified `meta.json` can be committed. See [privacy](../standards/privacy.md) and open fork **O9**.
4. **Refactor the DSP to read Zarr?** Confirm the EDF+→Zarr contract is go-forward (the DSP currently reads the EDF+ raw anchor directly), and `threshold=8` is recalibrated from mg-space to uint16 12-bit counts (otherwise PLM detection drifts silently).
5. ~~**One Zarr group multi-device, or one per device?**~~ **Not a question on this hardware.** There is one device and one clock, so every channel shares a timebase and any event may reference any channel. One group, no cross-device sync primitive needed. *(If a second device is ever added, this question comes back with it — do not treat the resolution as a general principle.)*
6. **Firmware provenance upgrade.** The C6 firmware emits **no** git hash and **no** equipment string. Change the build to emit full SHA + dirty flag + describe as a compile definition and have `logger.cpp` write it (the equipment field is 80-char-limited → likely a recording-start annotation TAL). Until then **every** recording from this hardware is non-audit-grade, not just those from dirty builds — is that acceptable for v0.1?
7. **Subsecond / whole-second time origin.** Firmware sets only whole-second start; accept whole-second alignment for v0.1, or have firmware pass a fractional start so the `+0.X` time-keeping TAL preserves it?
8. **Pinned environment.** `requirements.txt` is unpinned and the `requirements.lock` + `lockfile_hash` the spec references do not exist yet — generate a real lock (uv/pip-compile) and pin numpy/scipy/arch before the reproducibility block is non-fictional?
9. **Event id scope & hypnodensity.** Event ids are unique within a scoring (groups reference within-scoring ids). If the viewer needs human-confirms-algorithm cross-linking, switch to composite `(scoring_id, event_id)` keys? And if epoch granularity ever drops to per-second hypnodensity, the hypnogram becomes dense → moves to a Zarr probability matrix (deferred until on the roadmap).

---

**Key cross-slice reconciliations made (where reviewers found real breakage, the spec now reflects the fix, not the debate):** Zarr **v2** (single decision; z5/xtensor-zarr are v2-only per the [registry](https://zarr.dev/implementations/)); per-array **`storage` attr** as the one storage contract — now uniformly `digital` at capture, since `logger.cpp` writes `edfwrite_digital_samples` for all eleven channels, with `physical` surviving only in `derived/`; **mask-array** gap model (firmware writes 0, never digital_min), simplified to one mechanism now that no captured array is float; **interleaved min/max `(n,2)`** pyramid with gap-aware build and a real depth/spectrogram budget; single **canonical snake_case channel registry** in `meta.json.device.channels`; **`source_constants` vs `params`** split + `window_sec`/`--skip`/on-device-baseline capture; **`store_hash` (integrity) vs `value_digests` (re-derivation)** separated; per-storage-mode **equality tolerances** wired into the tests.

**Single-device hardware:** the ESP32-C6 is the sole raw anchor — one clock, one `signals/` group, one storage mode, hence the bit-exactness guarantees above. Two costs come with it: firmware provenance is **absent**, and the RIP unit story is muddied by the on-device count divisors. Accelerometry is 6 axes at 50 Hz in signed mg.

Sources: [Zarr implementations registry](https://zarr.dev/implementations/), [TensorStore zarr3 driver](https://google.github.io/tensorstore/driver/zarr3/index.html), [xtensor-zarr](https://github.com/xtensor-stack/xtensor-zarr), [z5](https://github.com/constantinpape/z5), [EDF+ spec](https://www.edfplus.info/specs/edfplus.html), [BDF+ description](https://www.teuniz.net/edfbrowser/bdfplus%20format%20description.html), [EDFlib](https://www.teuniz.net/edflib/), [zarr-python 3.0 migration](https://zarr.readthedocs.io/en/stable/user-guide/v3_migration/), [JSON Schema 2020-12](https://json-schema.org/draft/2020-12/schema). Repo facts grounded in `ESP32-C6-heart-idf/components/logger/logger.cpp`, `src_python/signal_processing.py`, `src_python/read_log.py`, `src_python/export_zarr.py`, `.gitignore`.

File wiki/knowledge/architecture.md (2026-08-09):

---
title: Component-2 Architecture
domain: knowledge
status: living
updated: 2026-07-19
summary: The canonical reference for ProtoSom's data pipeline after data leaves the device — the four-stage pipeline, the three-layer data model, and the C++ ingest / Python processing / TS web-app language boundary that meets at the Zarr store plus metadata.
---

# Component-2 Architecture

ProtoSom has two components. **Component 1** is the hardware data acquisition (an ESP32-C6 on a
bespoke breadboard, with a KiCad PCB in progress, owned by Dmitry). **Component 2** is everything *after* the data leaves the device:
ingest, signal processing, the viewer, and the report. This page is the spine — the canonical
reference for how component 2 is structured. Everything else in the wiki hangs off it.

This is a **proof-of-concept**. It is **not** a regulated medical device, but it voluntarily adopts
[IEC 62304](../standards/coding.md) software discipline: traceability, test coverage, and
reproducibility/auditability. Those three constraints shape every decision below.

> The original design brief and its open questions live in
> [`doc/global_architecture.md`](../../doc/global_architecture.md). This page records the **settled**
> architecture; where something is still undecided it links to [open forks](../state/decisions.md).

---

## 1. The four-stage pipeline

Data flows through four stages, left to right. Each stage has a single responsibility and a
well-defined handoff:

```
   device  ──▶  C++ ingest  ──▶  Python processing  ──▶  the TS web app
  (comp. 1)      (Dmitry)          (Dmitry)                 (Leon)
```

| Stage | Owner | What it does | Reads | Writes |
|---|---|---|---|---|
| **device** | comp. 1 (Dmitry) | Acquires biosignals + audio, emits the [raw anchor](#layer-1--raw-capture-the-raw-anchor) | sensors | EDF+ (biosignals), FLAC (audio) |
| **C++ ingest** | Dmitry | Converts the raw capture into the **raw Zarr** layer; extracts header metadata; may own the [clinical export](#layer-3--clinical-export) | raw anchor | raw Zarr ([working store](#layer-2--working-store)) |
| **Python processing** | Dmitry | The signal processing + ML — the heart of the system | raw Zarr | derived Zarr + `events.json` + `meta.json` |
| **the TS web app** | Leon | Reads the [Zarr boundary](#5-the-zarr-boundary--a-language-neutral-contract) + metadata and presents it — charts, spectrogram, UI | Zarr + metadata | **nothing** (read-only) |

The data the chart needs is **screen-resolution for the visible window**, not the whole recording —
see [§4 the batch + on-demand model](#4-the-batch--on-demand-invocation-model) and
[viewer](viewer.md).

---

## 2. The three-layer data model

ProtoSom keeps **three** representations of a recording. Only the middle one is mutable; the others
are immutable or ephemeral. This separation is what makes the pipeline auditable: you can always
regenerate the working store from the raw anchor and prove the result. ([Format detail](data-formats.md).)

### Layer 1 — Raw capture (the raw anchor)

Whatever the device emits, byte-for-byte: **EDF+** for biosignals (read/written via `edflib`; **BDF+**
for future 24-bit EEG), **FLAC** for audio, time-anchored to the biosignal timeline. It is
**immutable and content-hashed** — the provenance anchor that every derived product is stamped
against. It is **never modified** by any stage of component 2.

The concrete raw anchor is the **11-channel EDF+** written by the ESP32-C6
([`logger.cpp`](../../ESP32-C6-heart-idf/components/logger/logger.cpp)) — Thoracic + Abdomen
(LDC1612 RIP belts, 50 Hz), Flow (SDP800, mbar, 50 Hz), ECG (AD8232 ADC, 100 Hz),
Accel0X/Y/Z + Accel1X/Y/Z (MMA8451 ×2, mg, 50 Hz), and RR (ms, 2.5 Hz — currently a dead channel
with no live source); see the `SigDef` table at
[`logger.cpp:473`](../../ESP32-C6-heart-idf/components/logger/logger.cpp) and
[hardware](hardware.md) for the full layout.

### Layer 2 — Working store

A **Zarr group per recording** — every dense signal is its own array, chunked along the time axis —
plus two JSON sidecars:

- **`meta.json`** — metadata + the provenance block (what raw anchor, what code version, what params
  produced this).
- **`events.json`** — sparse annotations (PLM/LM events, apnea/hypopnea, snore classifications,
  markers).

Two producers write this layer:

- **raw Zarr** — produced by **C++ ingest** from the raw anchor.
- **derived Zarr** — produced by **Python processing** (filtered signals, feature arrays, the
  audio spectrogram array, etc.).

Per-array Zarr attribute `storage = physical | digital` records the EDF write path. The ESP32-C6's
`logger.cpp` writes **digital** integers via `edfwrite_digital_samples`, so every array ingested
from a current recording carries `storage=digital`; the attribute is kept general because the
derived layer also holds calibrated float arrays. The working store is **regenerable from the raw anchor**, so it can be
deleted and rebuilt at will. It is the only mutable layer and the meeting point of the whole
architecture. ([Zarr v2 + Blosc/zstd rationale](data-formats.md), [decisions](../state/decisions.md).)

> **Note on the current code.** [`src_python/export_zarr.py`](../../src_python/export_zarr.py) reflects
> the earlier single-codebase prototype: Python opens the group with
> `zarr.open_group(..., zarr_format=2)` ([`export_zarr.py:56`](../../src_python/export_zarr.py)),
> creates one array per signal, and writes `meta.json` + `events.json` sidecars following the
> canonical nested schema — `subject`/`recording`/`stats`/`layers`/`provenance`, with the full
> git SHA + dirty flag under `provenance.pipeline.git`. Under the settled architecture the
> **raw** Zarr is produced by C++ ingest and the **derived** Zarr + metadata by Python processing;
> the Python writer above is the seed of the derived-layer producer.

### Layer 3 — Clinical export

**EDF+/BDF+ regenerated on demand** for interop with tools like EDFBrowser. It is **never stored** —
it is produced from the derived layer when a clinician asks, then handed off. The export scrubs the
EDF+ header patient name/DOB to produce a shareable de-identified file. May be owned by C++ ingest.

```
 ┌──────────────────┐      ┌────────────────────────┐      ┌─────────────────────┐
 │ Layer 1: RAW      │      │ Layer 2: WORKING STORE  │      │ Layer 3: CLINICAL   │
 │ EDF+ / FLAC       │─────▶│ Zarr arrays + JSON      │─────▶│ EDF+/BDF+ on demand │
 │ immutable, hashed │ regen│ mutable, regenerable    │ regen│ never stored        │
 │ the raw anchor    │◀─────│ the working store       │      │ de-identified       │
 └──────────────────┘ never └────────────────────────┘      └─────────────────────┘
       provenance       raw=C++ ingest · derived=Python proc.    interop / share
```

---

## 3. The language boundary

The authoritative split is **three languages**, each chosen for what it is best at. The governing
principle:

> **C++ ingests, Python processes, TypeScript presents. The three meet at the Zarr store + metadata.**

| Layer | Language | Owner | Responsibility | Reads | Writes |
|---|---|---|---|---|---|
| **C++ ingest** | C++ (edflib + TensorStore/z5) | Dmitry | Device acquisition + convert raw EDF+/FLAC → **raw Zarr**; extract header metadata; may own clinical export | raw anchor | raw Zarr |
| **Python processing** | Python (scipy/numpy/scikit/PyTorch) | Dmitry | Signal processing + ML: baseline removal, AASM PLM/LM, HRV, airflow filtering, apnea/hypopnea, snore VOTE/MFCC, … | raw Zarr | derived Zarr + `events.json` + `meta.json` |
| **the TS web app** | TypeScript (zarrita.js + ECharts/uPlot) | Leon | Charts, spectrogram, UI, the slicing server | Zarr + metadata | **never writes Zarr** |

**Why these three:**

- **C++ for ingest** — performance and medical-compliance friendliness, and it reuses the existing
  `edflib`-based firmware
  ([`logger.cpp`](../../ESP32-C6-heart-idf/components/logger/logger.cpp)). Writes Zarr via a C++
  Zarr library (TensorStore / z5 / xtensor-zarr).
- **Python for processing** — there is a *copious* amount of feature-finding work ("finding salient
  features in the signals"), and Python is the de-facto standard for it. The current processing lives
  in [`src_python/signal_processing.py`](../../src_python/signal_processing.py)
  (`remove_baseline`, `count_plm` for AASM PLM, `compute_hrv` for RMSSD). Reads raw Zarr → writes the
  derived layer + metadata (including provenance). See [signal processing](signal-processing.md).
- **TypeScript for the web app** — reads the [Zarr boundary](#5-the-zarr-boundary--a-language-neutral-contract)
  via `zarrita.js` and presents it ([`src_web/src/main.ts`](../../src_web/src/main.ts) loads `meta`
  then the Zarr arrays and renders with ECharts; the current loader uses `zarr.js` via
  [`src_web/src/zarr_loader.ts`](../../src_web/src/zarr_loader.ts)). It **never** writes Zarr.
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

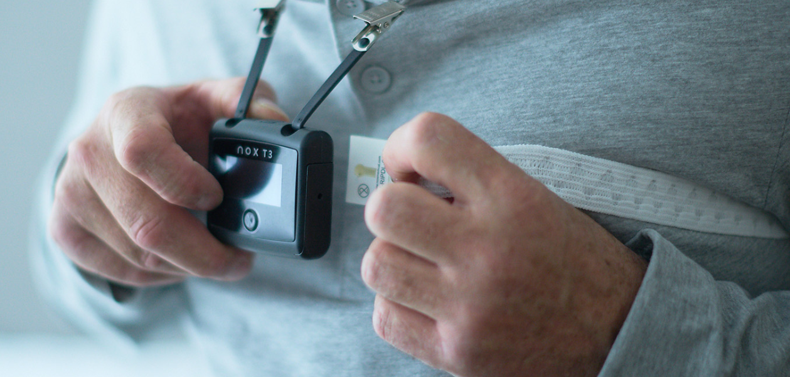
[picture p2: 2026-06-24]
Hardware/doc/reference_img/rip_belt.png

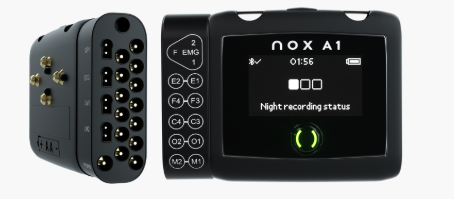
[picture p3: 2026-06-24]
Hardware/doc/reference_img/nox_A1_psg_device.png

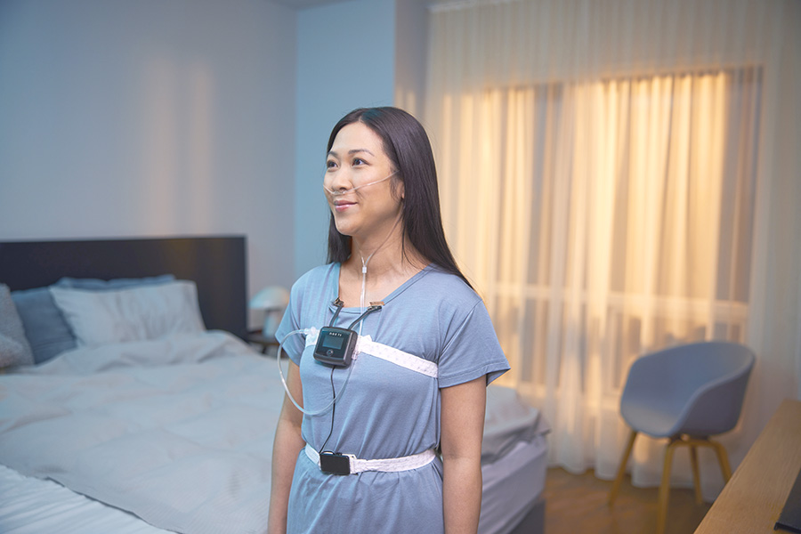
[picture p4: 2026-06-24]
Hardware/doc/reference_img/Nox-RIP-Belts-optimized.jpg

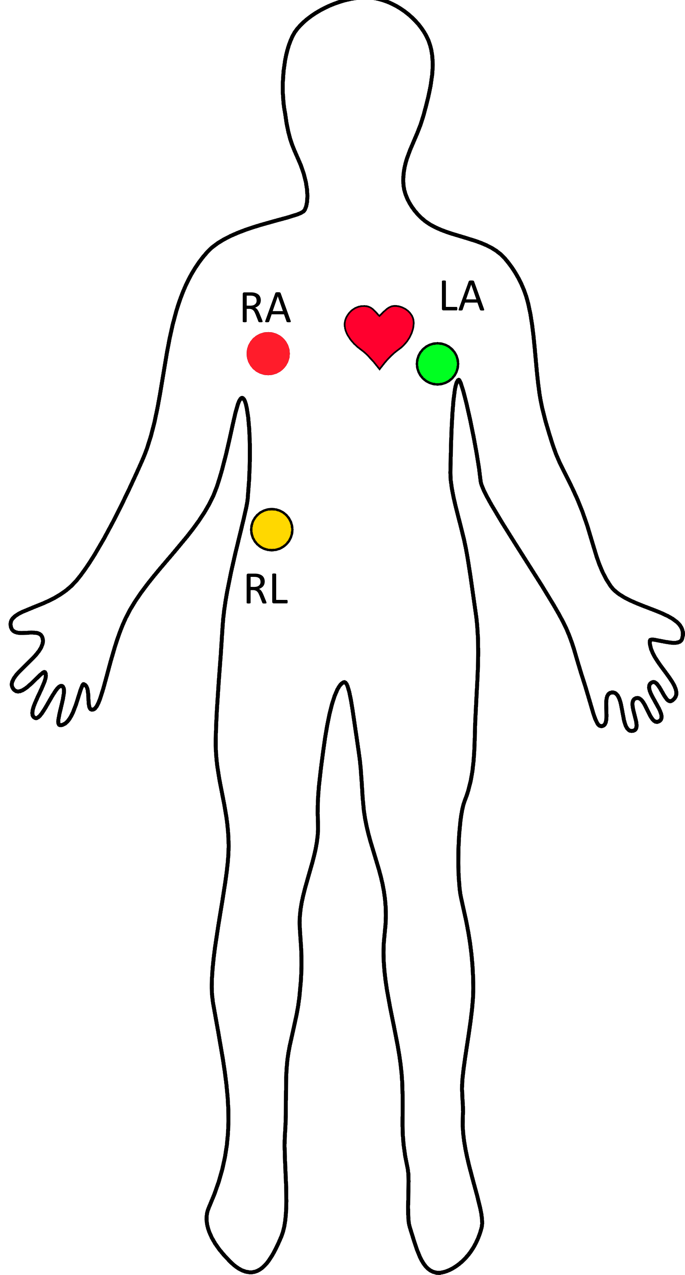
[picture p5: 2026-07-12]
Hardware/Datasheets/AD8232/body_EEG_electrode_sites.png

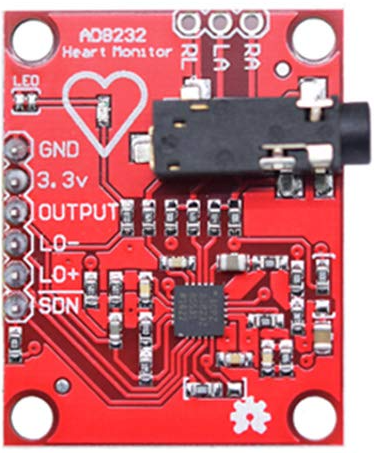
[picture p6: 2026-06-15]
Hardware/Datasheets/AD8232/AD8232 breakout board.png

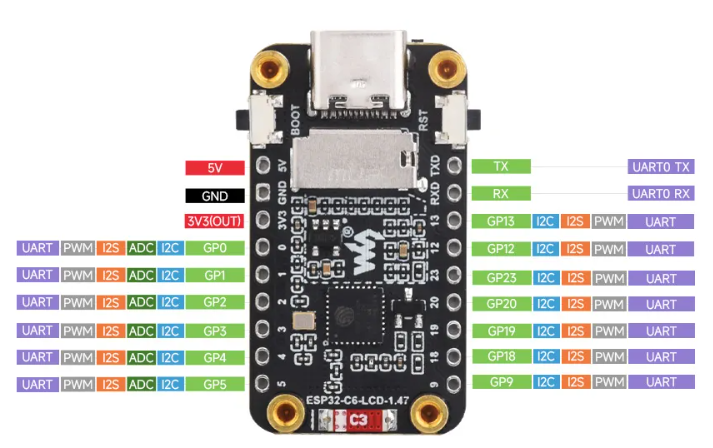
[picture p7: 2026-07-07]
ESP32-C6-heart-idf/vendor_ref/ESP32-C6-LCD-1.47 pinout.png

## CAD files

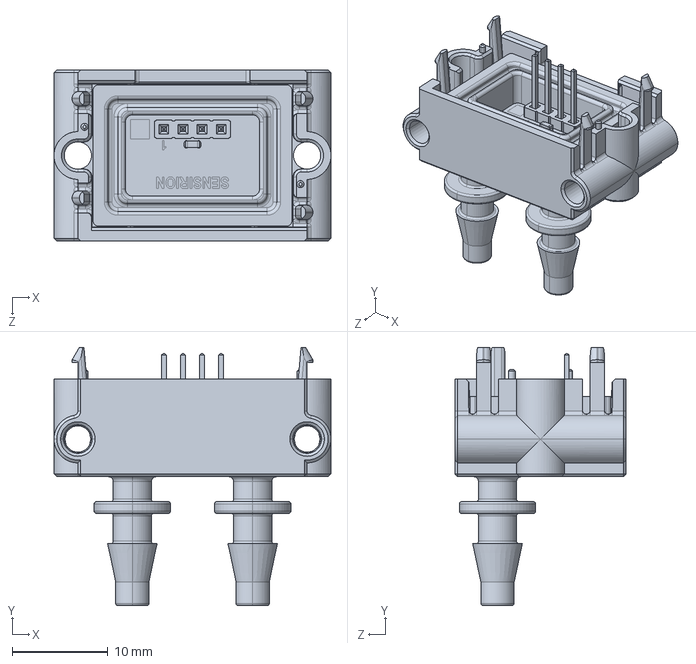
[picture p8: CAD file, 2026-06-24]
Hardware/3D Models/Sensirion_Differential_Pressure_Sensors_SDP810_STEP_file.step
29.0 x 27.1 x 18.0 mm

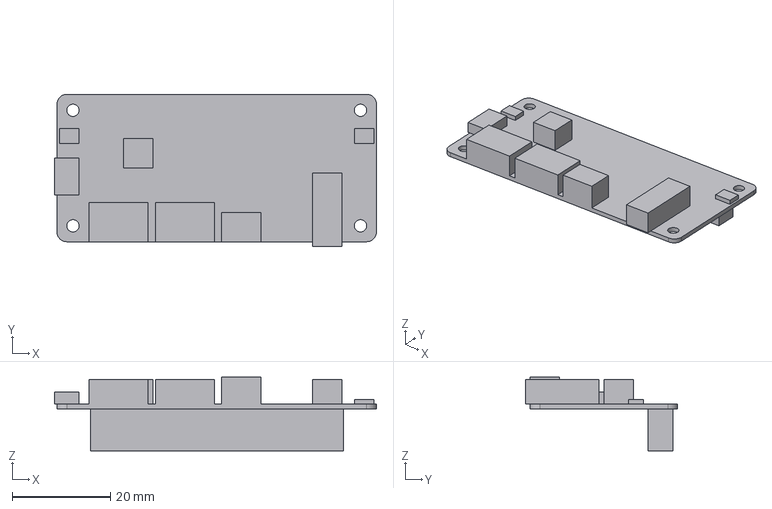
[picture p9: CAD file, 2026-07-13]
Hardware/proto/Respeaker2MicPiHat.step
65.5 x 31.0 x 15.0 mm

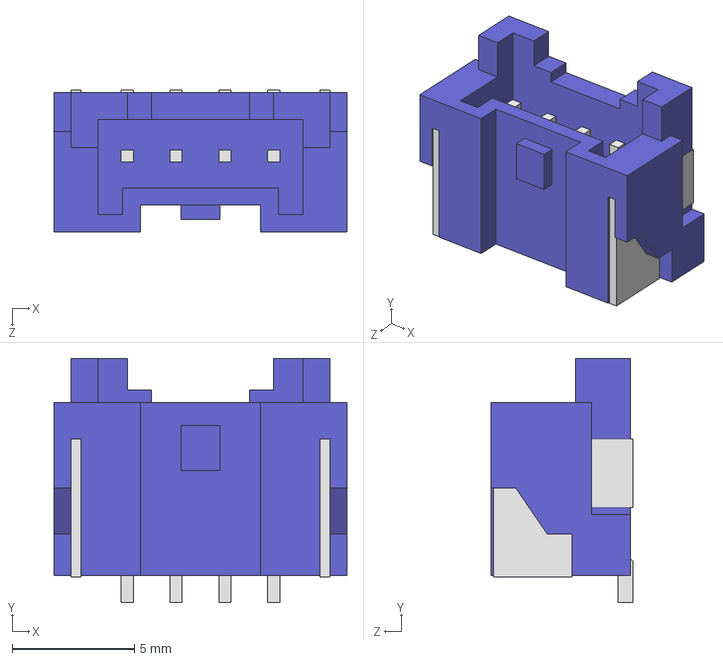
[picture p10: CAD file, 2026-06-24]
Hardware/3D Models/SM04B-PASS-TB.STEP
12.0 x 10.0 x 5.80 mm

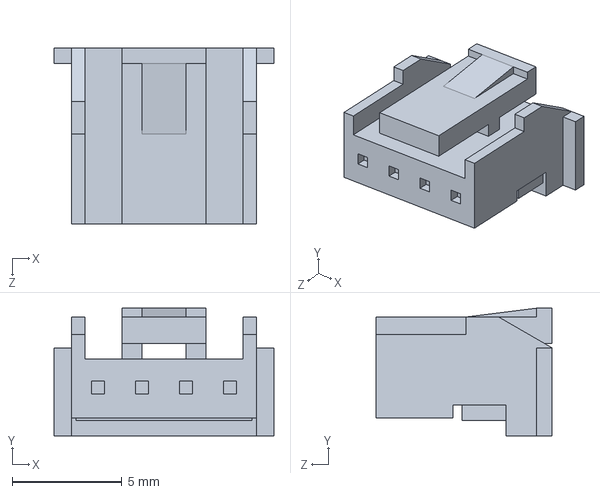
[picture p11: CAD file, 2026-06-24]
Hardware/3D Models/PAP-04V-S.STEP
10.0 x 5.80 x 8.00 mm

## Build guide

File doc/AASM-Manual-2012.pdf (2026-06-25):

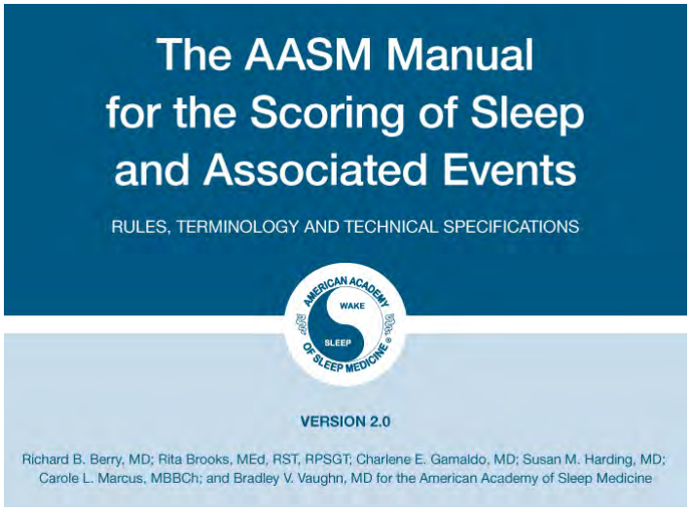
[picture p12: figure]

Berry RB, Brooks R, Gamaldo CE, Harding SM, Marcus CL, Vaughn BV and Tangredi MM for the American Academy of Sleep Medicine. The AASM Manual for the Scoring of Sleep and Associated Events: Rules, Terminology and Technical Specifications, Version 2.0. www.aasmnet.org, Darien, Illinois: American Academy of Sleep Medicine, 2012.

## General Scoring of Sleep Stages

### 1. The following terminology should be used for the stages of sleep in adults:N1

a. Stage W (Wakefulness)
b. Stage N1 (NREM 1)
c. Stage N2 (NREM 2)
d. Stage N3 (NREM 3)
e. Stage R (REM)

### 2. Score epochs using the following parameters:

a. Score sleep stages in 30-second, sequential epochs commencing at the start of the study.
b. Assign a stage to each epoch.
c. If 2 or more stages coexist during a single epoch, assign the stage comprising the greatest portion of the epoch.

Note 1. Stage N3 represents slow wave sleep and replaces the Rechtschatten and Kales nomenclature of stage 3 and stage 4 sleep.

WAKE

### 1. Score in accordance with the following definitions:

Alpha rhythm: Trains of sinusoidal 8-13 Hz activity recorded over the occipital region with eye closure, attenuating with eye opening.

Eye blinks: Conjugate vertical eye movements at a frequency of 0.5-2 Hz present in wakefulness with the eyes open or closed.

Reading eye movements: Trains of conjugate eye movements consisting of a slow phase followed by a rapid phase in the opposite direction as the subject reads.

Rapid eye movements (REM): Conjugate, irregular, sharply peaked eye movements with an initial deflection usually lasting <500 msec. While rapid eye movements are characteristic of stage R sleep, they may also be seen in wakefulness with eyes open when subjects scan the environment.

Slow eye movements (SEM): Conjugate, reasonably regular, sinusoidal eye movements with an initial deflection usually lasting >500 msec.

### 2. Score epochs as stage W when more than 50% of the epoch has alpha rhythm over the

occipital region.

3. Score epochs without visually discernible alpha rhythm as stage W if ANY of the following are present:
a. Eye blinks at a frequency of 0.5-2 Hz
b. Reading eye movements
c. Irregular, conjugate rapid eye movements associated with normal or high chin muscle tone

Note 1. Stage W represents the waking state, ranging from full alertness through early stages of drowsiness. Electrophysiological and psychophysiological markers of drowsiness may be present during stage W and may persist
into | stage | N1.

Note 2. In stage W, the majority of individuals with eyes closed will demonstrate alpha rhythm. The EEG pattern with eyes open consists of low-amplitude activity (chiefly beta and alpha frequencies) without the rhythmicity of alpha rhythm. About 10% of subjects do not generate alpha rhythm on eye closure, and a further 10% may generate a limited alpha rhythm. In these subjects, the occipital EEG activity is similar during eye opening and eye closure.

Note 3. The EOG during wakefulness may demonstrate rapid eye blinks at a frequency of about 0.5-2 Hz. As drowsiness develops, the frequency of blinking slows, and eye blinks may be replaced by slow eye movements, even in the presence of continued alpha rhythm. If the eyes are open, voluntary rapid eye movements or reading eye
movements | may | be | seen.

Note 4. The chin EMG during stage W is of variable amplitude but is usually higher than during sleep stages.

Note 5. Time with the patient disconnected from the recording equipment should be scored as stage W. Brief episodes of sleep during this time, if they occur, are not considered significant for the stage scoring summary.

## Scoring Stage N1

### 1. Score in accordance with the following definitions:

Slow eye movements (SEM): Conjugate, reasonably regular, sinusoidal eye movements with an initial deflection usually lasting >500 msec.

Low-amplitude, mixed-frequency EEG activity: Low-amplitude, predominantly 4-7 Hz activity.

Vertex sharp waves (V waves): Sharply contoured waves with duration <0.5 seconds maximal over the central region and distinguishable from the background activity.

Sleep onset: The start of the first epoch scored as any stage other than stage W. (In most subjects this will usually be the first epoch of stage N1.)

2. In subjects who generate alpha rhythm, score stage N1 if the alpha rhythm is attenuated and replaced by low-amplitude, mixed-frequency activity for more than 50% of the epoch.N1,N2,N3
3. In subjects who do not generate alpha rhythm, score stage N1 commencing with the earliest of ANY of the following phenomena:N1,N2,N3,N4
a. EEG activity in range of 4-7 Hz with slowing of background frequencies by ≥1 Hz from those of stage W
b. Vertex sharp waves
c. Slow eye movements

Note 1. Vertex sharp waves may be present but are not required for scoring stage N1.

Note 2. The EOG will often show slow eye movements in stage N1, but these are not required for scoring.

Note 3. During stage N1, the chin EMG amplitude is variable, but often lower than in stage W.

Note 4. As slow eye movements often commence before attenuation of alpha rhythm, sleep latency may be slightly shorter for some individuals who do not generate alpha rhythm compared to those who do.

## Scoring Stage N2

### 1. Score in accordance with the following definitions:

K complex: A well-delineated, negative, sharp wave immediately followed by a positive component standing out from the background EEG, with total duration ≥0.5 seconds, usually maximal in amplitude when recorded using frontal derivations. For an arousal to be associated with a K complex, the arousal must either be concurrent with the K complex or commence no more than 1 second after termination of the K complex.

Sleep spindle: A train of distinct waves with frequency 11-16 Hz (most commonly 12-14 Hz) with a duration ≥0.5 seconds, usually maximal in amplitude in the central derivations.

2. Begin scoring stage N2 (in absence of criteria for N3) if EITHER OR BOTH of the following occur during the first half of that epoch or the last half of the previous epoch:N1,N2,N3,N4
a. One or more K complexes unassociated with arousals
b. One or more trains of sleep spindles

### 3. Continue to score epochs with low-amplitude, mixed-frequency EEG activity without K

complexes or sleep spindles as stage N2 if they are preceded by epochs containing EITHER of the following:

a. K complexes unassociated with arousals
b. Sleep spindles

### 4. End stage N2 sleep when ONE of the following events occurs:N5,N6

a. Transition to stage W
b. An arousal (change to stage N1 until a K complex unassociated with an arousal or a sleep spindle occurs) (see Figure 4)
c. A major body movement followed by slow eye movements and low-amplitude, mixed-frequency EEG without non-arousal associated K complexes or sleep spindles (Score the epoch following the major body movement as stage N1; score the epoch as stage N2 if there are no slow eye movements; the epoch containing the body movement is scored using the criteria under heading J) (http://www.aasmnet.org/scoringmanual/html/JScoringEpochswithMajorBodyMovem.html) (see Figure 5)
d. Transition to stage N3
e. Transition to stage R

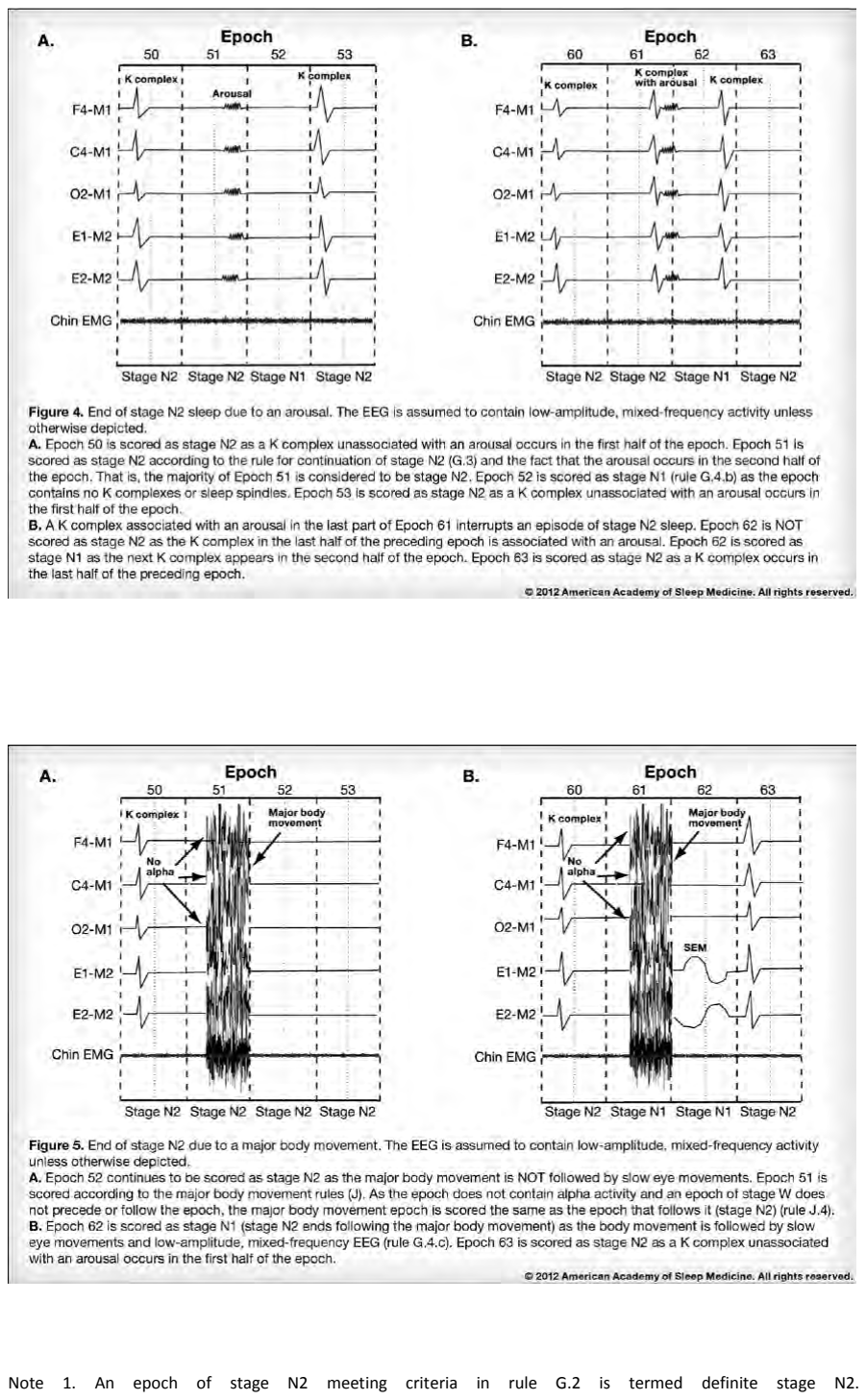
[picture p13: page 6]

Note 1. An epoch of stage N2 meeting criteria in rule G.2 is termed definite stage N2.

Note 2. Continue to score stage N1 for epochs with arousal-associated K complexes unless they contain sleep
spindles | or | K | complexes | not | associated | with | arousals.

Note 3. For the purposes of scoring N2 sleep, arousals are defined according to the arousal rule in section V.A.1. (http://www.aasmnet.org/scoringmanual/html/AScoringArousals.html)

Note 4. Although sleep spindles and frequency changes associated with arousals are more typically noted in the central and occipital derivations respectively, these events should be used to score sleep even if they are only noted
in | the | frontal | derivations.

Note 5. The EOG usually shows no eye movement activity during stage N2 sleep, but slow eye movements may
persist | in | some | subjects.

Note 6. In stage N2, the chin EMG is of variable amplitude, but is usually lower than in stage W, and may be as low as in stage R sleep.

## Scoring Stage N3

### 1. Score in accordance with the following definition:N1

Slow wave activity: Waves of frequency 0.5 Hz-2 Hz and peak-to-peak amplitude >75 μV, measured over the frontal regions

### 2. Score stage N3 when ≥20% of an epoch consists of slow wave activity, irrespective of

age.N2,N3,N4

Note 1. K complexes would be considered slow waves if they meet the definition of slow wave activity.

Note 2. Sleep spindles may persist in stage N3 sleep.

Note 3. Eye movements are not typically seen during stage N3 sleep.

Note 4. In stage N3, the chin EMG is of variable amplitude, often lower than in stage N2 sleep and sometimes as low as in stage R sleep.

## Scoring Stage R

### 1. Score in accordance with the following definitions:

Rapid eye movements (REM): Conjugate, irregular, sharply peaked eye movements with an initial deflection usually lasting <500 msec.

Low chin EMG tone: Baseline EMG activity in the chin derivation no higher than in any other sleep stage and usually at the lowest level of the entire recording.

Sawtooth waves: Trains of sharply contoured or triangular, often serrated, 2-6 Hz waves maximal in amplitude over the central head regions and often, but not always, preceding a burst of rapid eye movements.

Transient muscle activity: Short irregular bursts of EMG activity usually with duration <0.25 seconds superimposed on low EMG tone. The activity may be seen in the chin or anterior tibial EMG derivations, as well as in EEG or EOG deviations, the latter indicating activity of cranial nerve innervated muscles (facial muscles and scalp). The activity is maximal in association with rapid eye movements.

### 2. Score stage R sleep in epochs with ALL of the following phenomena:N1,N2,N3

a. Low-amplitude, mixed-frequency EEG
b. Low chin EMG tone
c. Rapid eye movements
3. Continue to score stage R sleep, even in the absence of rapid eye movements, for epochs following one or more epochs of stage R as defined in rule I.2 above, IF the EEG continues to show low-amplitude, mixed-frequency activity without K complexes or sleep spindles AND the chin EMG tone remains low for the majority of the epoch.N4 (see Figure 6)

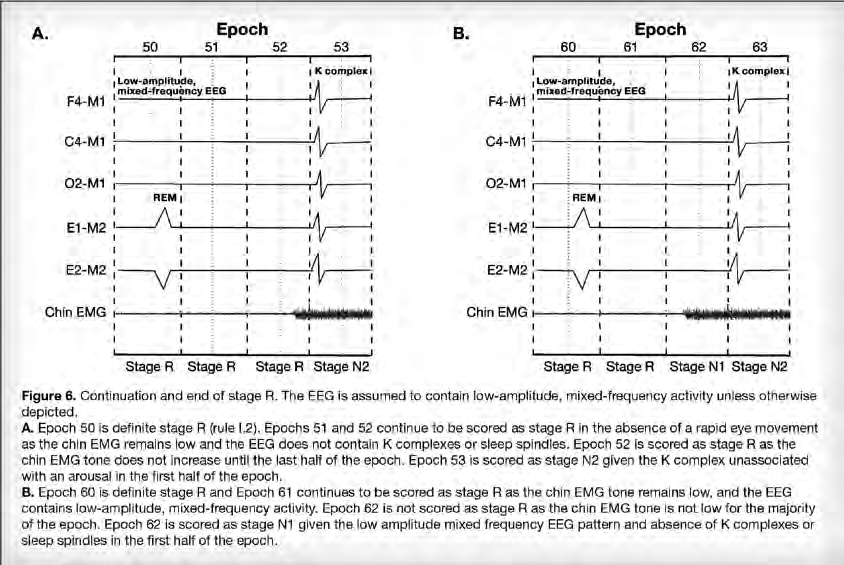
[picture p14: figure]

Stop scoring stage R sleep when ONE OR MORE of the following occur:

a. There is a transition to stage W or N3 b. An increase in chin EMG tone above the level of stage R is seen for the majority of the epoch and criteria for stage N1 are met (see Figure 7)
c. An arousal occurs followed by low-amplitude, mixed-frequency EEG and slow eye movements (Score the epoch as stage N1; if there are no slow eye movements and chin EMG tone remains low, continue to score as stage R) (see Figure 8)
d. A major body movement followed by slow eye movements and low-amplitude, mixed-frequency EEG without non-arousal associated K complexes or sleep spindles (Score the epoch following the major body movement as stage N1; if no slow eye movements and the EMG tone remains low, continue to score as stage R; the epoch containing the body movement is scored using the criteria under heading J) (http://www.aasmnet.org/scoringmanual/html/JScoringEpochswithMajorBodyMovem.html) (see Figure 9)
e. One or more non-arousal associated K complexes or sleep spindles are present in the first half of the epoch in the absence of rapid eye movements, even if chin EMG tone remains low (Score the epoch as stage N2) (see Figure 10)

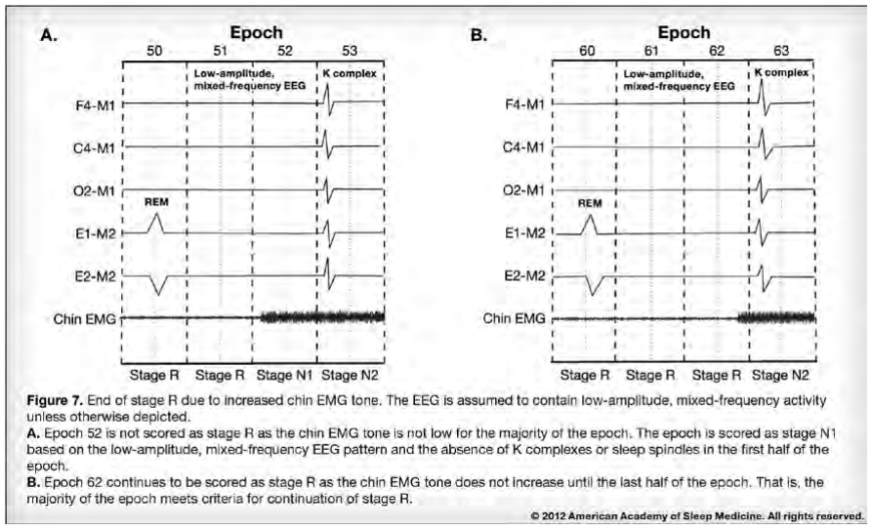
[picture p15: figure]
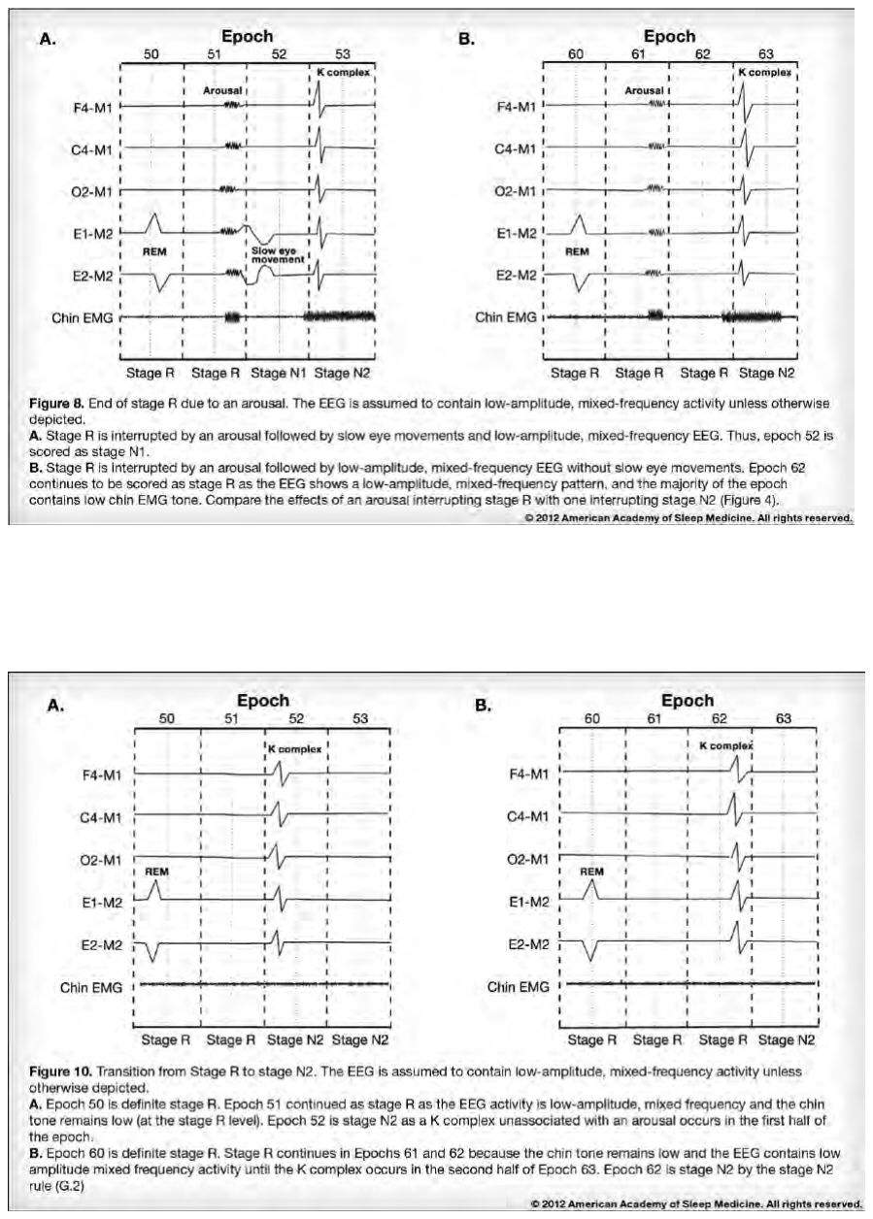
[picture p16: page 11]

Score epochs at the transition between stage N2 and stage R as follows: N1,N2,N3,N4,N5,N6

a. In between epochs of definite stage N2 and definite stage R, score an epoch with a distinct drop in chin EMG in the first half of the epoch to the level seen in stage R as stage R even in the absence of rapid eye movements, if ALL of the following criteria are met: (see Figure 11)
i. Absence of non-arousal associated K complexes

ii. Absence of sleep spindles

b. In between epochs of definite stage N2 and definite stage R, score an epoch with a distinct drop in chin EMG in the first half of the epoch to the level seen in stage R as stage N2 if ALL of the following criteria are met: (see Figure 12A)
i. Presence of non-arousal associated K complexes or sleep spindles

ii. Absence of rapid eye movements

c. In between epochs of definite stage N2 with minimal chin EMG tone and definite stage R without further drop in chin EMG tone, score epochs as stage R even in the absence of rapid eye movements, if ALL of the following are met: (see Figure 12B)
i. Absence of non-arousal associated K complexes

ii. Absence of sleep spindles

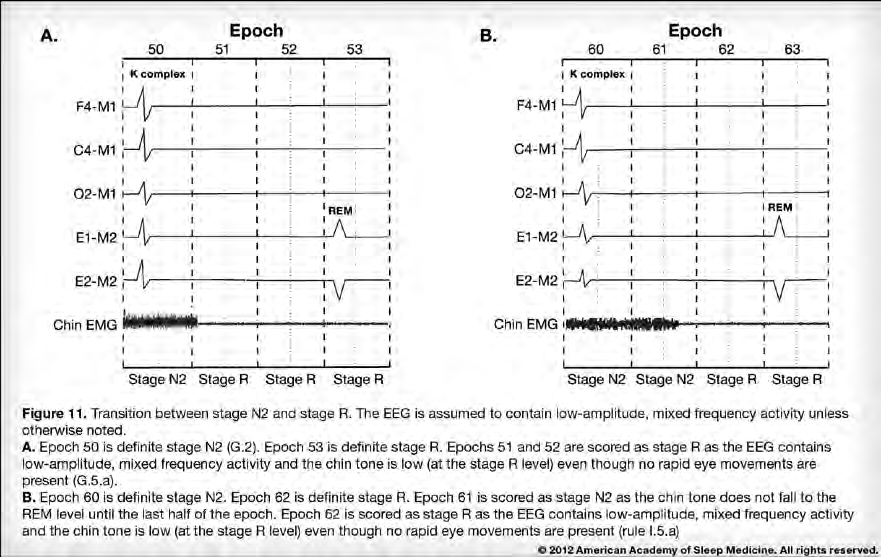
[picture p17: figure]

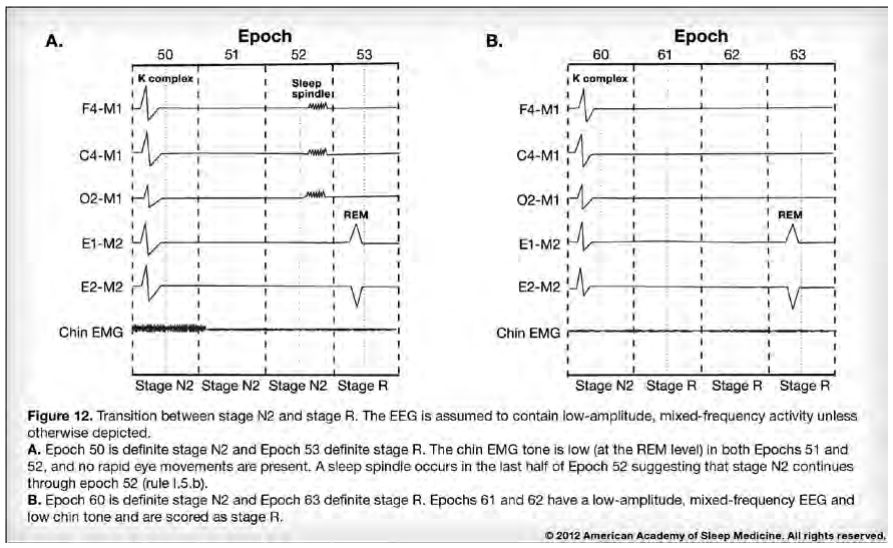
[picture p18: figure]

Note 1. Epochs defined by rule I.2 are called epochs of definite stage R. Such epochs usually do not contain K complexes or sleep spindles. However, especially in the first REM sleep period of the night, K complexes or sleep spindles may be interspersed among epochs of what otherwise appears to be stage R sleep. Epochs defined by rule I.2 are scored as stage R even in the presence of K complexes or sleep spindles. In the absence of rapid eye movements, epochs containing sleep spindles or K complexes are not scored as stage R even if they contain low chin EMG tone.

Note 2. Definite stage N2 refers to epochs defined by G.2. (http://www.aasmnet.org/scoringmanual/html/GScoringStageN2.html) The epoch contains one or both of the following: one or more sleep spindles or one or more K complexes in the first half of the epoch, and the epoch does not meet criteria for stage N3.

Note 3. Low-amplitude, mixed-frequency activity in stage R resembles that seen in stage N1. In some individuals, a greater amount of alpha activity can be seen in stage R than in stage N1. The alpha frequency in stage R often is 1-2 Hz slower than during wakefulness.

Note 4. Sawtooth waves or transient muscle activity are strongly supportive of the presence of stage R sleep and may be helpful when the stage is in doubt, however, they are not required for scoring stage R.

Note 5. There are no rules specifically dealing with stage N1-R transitions. Stage R sleep will only commence when rapid eye movements are seen in association with low muscle tone and the typical EEG.

Note 6. At times, especially in the first REM sleep period of the night, K complexes or sleep spindles may be interspersed among epochs of what otherwise appears to be stage R sleep. The above rules indicate that epochs with rapid eye movements should be scored as stage R even in the presence of K complexes or spindles. However, if rapid eye movements are absent, subsequent epochs with K complexes or spindles should be scored as stage N2, even if chin muscle tone remains low.

## Scoring Epochs with Major Body Movements

### 1. Score in accordance with the following definition:

Major body movement: Movement and muscle artifact obscuring the EEG for more than half an epoch to the extent that the sleep stage cannot be determined.

2. If alpha rhythm is present for part of the epoch (even <15 seconds duration), score as stage W.
3. If no alpha rhythm is discernible, but an epoch scorable as stage W either precedes or follows the epoch with a major body movement, score as stage W.
4. Otherwise, score the epoch as the same stage as the epoch that follows it.

## Scoring Arousals

1. Score arousal during sleep stages N1, N2, N3, or R if there is an abrupt shift of EEG frequency including alpha, theta and/or frequencies greater than 16 Hz (but not spindles) that lasts at least 3 seconds, with at least 10 seconds of stable sleep preceding the change. Scoring of arousal during REM requires a concurrent increase in submental EMG lasting at least 1 second.N1,N2,N3

Note 1. Arousal scoring should incorporate information from both the occipital and central derivations.

Note 2. Arousal scoring can be improved by the use of additional information in the recording such as respiratory events and/or additional EEG channels. Scoring of arousals, however, cannot be based on this additional information alone and such information does not modify any of the arousal scoring rules.

Note 3. Arousals meeting all scoring criteria but occurring during an awake epoch in the recorded time between "lights out" and "lights on" should be scored and used for computation of the arousal index.

## Scoring Cardiac EventsN1,N2

1. Score sinus tachycardia during sleep for a sustained sinus heart rate of greater than 90 beats per minute for adults.N3,N4
2. Score bradycardia during sleep for a sustained heart rate of less than 40/minute for ages 6 years through adult.N4

### 3. Score asystole for cardiac pauses greater than 3 seconds for ages 6 years through

adult.

4. Score wide complex tachycardia for a rhythm lasting a minimum of 3 consecutive beats at a rate greater than 100 per minute with QRS duration of greater than or equal to 120 msec.
5. Score narrow complex tachycardia for a rhythm lasting a minimum of 3 consecutive beats at a rate of greater than 100 per minute with QRS duration of less than 120 msec.
6. Score atrial fibrillation if there is an irregularly irregular ventricular rhythm associated with replacement of consistent P waves by rapid oscillations that vary in size, shape, and timing.

Note 1. Significant arrhythmias such as heart block should be reported if the quality of the single lead is sufficient for accurate scoring.

Note 2. Ectopic beats should be reported if felt to be clinically significant.

Note 3. Sinus rates vary according to age in children, with faster rates in young children as compared to adults. For typical sinus rates in children, refer to the Cardiac Task Force review paper.1

Note 4. Sustained sinus bradycardia or tachycardia is defined by more than 30 seconds of a stable rhythm to distinguish it from transient responses, associated sleep disordered breathing events or arousals.

## Scoring Periodic Limb Movements in Sleep (PLMS)

### 1. The following define a significant leg movement (LM) event:N1,N2,N3,N4

a. The minimum duration of a LM event is 0.5 seconds.
b. The maximum duration of a LM event is 10 seconds.
c. The minimum amplitude of a LM event is an 8 μV increase in EMG voltage above resting EMG.
d. The timing of the onset of a LM event is defined as the point at which there is an 8 μV increase in EMG voltage above resting EMG.
e. The timing of the ending of a LM event is defined as the start of a period lasting at least 0.5 seconds during which the EMG does not exceed 2 μV above resting EMG.

### 2. The following define a PLM series:N5,N6

a. The minimum number of consecutive LM events needed to define a PLM series is 4 LMs.
b. The minimum period length between LMs (defined as the time between onsets of consecutive LMs) to include them as part of a PLM series is 5 seconds.
c. The maximum period length between LMs (defined as the time between onsets of consecutive LMs) to include them as part of a PLM series is 90 sec.
d. Leg movements on 2 different legs separated by less than 5 seconds between movement onsets are counted as a single leg movement.

Note 1. An LM should not be scored if it occurs during a period from 0.5 seconds preceding an apnea, hypopnea, RERA or sleep-disordered-breathing event to 0.5 seconds following.

Note 2. Surface electrodes should be placed longitudinally and symmetrically around the middle of the muscle so that they are 2-3 cm apart or 1/3 of the length of the anterior tibialis muscle, whichever is shorter. Both legs should be monitored for the presence of the leg movements. Separate channels for each leg are strongly preferred. Combining electrodes from the 2 legs to give 1 recorded channel may suffice for some clinical settings, although it should be recognized that this strategy may reduce the number of detected LMs. Movements of the upper limbs may be sampled if clinically indicated.

Note 3. The movement rule A.1 defines a significant leg movement event by absolute increase in μV above resting baseline for the anterior tibialis EMG. This requires a stable resting EMG for the relaxed anterior tibialis whose absolute signal should be no greater than +10 μV between negative and positive deflection (±5 μV ) or +5 μV for rectified signals.

Note 4. Use of 60 Hz (notch) filters should be avoided. Impedances need to be less than 10,000 Ω. Less than 5,000 Ω is preferred but may be difficult to obtain. Sensitivity limits of -100 and +100 μV (upper/lower) are preferred.

Note 5. An arousal and a PLM should be considered associated with each other when there is <0.5 seconds between the end of one event and the onset of the other event regardless of which is first.

Note 6. When two periodic limb movements occur with an interval of less than 10 seconds and each is associated with a 3 second arousal, only the first arousal should be scored although both limb movements may be scored. In this scenario, the arousal index and PLMS arousal index, but not the PLMS index, would be influenced by not scoring the second "arousal."

## Scoring Alternating Leg Muscle Activation (ALMA)

### 1. The following define ALMA:N1,N2,N3

a. The minimum number of discrete and alternating EMG bursts of leg muscle activity needed to score an ALMA series is 4 ALMAs.
b. The minimum frequency of the alternating EMG bursts in ALMA is 0.5 Hz.
c. The maximum frequency of the alternating EMG bursts in ALMA is 3.0 Hz.

Note 1. ALMAs alternate between legs.

Note 2. The usual range for duration of ALMA is 100-500 msec.

Note 3. ALMA may simply be a benign movement phenomenon associated with characteristic EMG patterns as there have been no reported clinical consequences.

## Scoring Hypnagogic Foot Tremor (HFT)

### 1. The following define HFT:N1,N2

a. The minimum number of EMG bursts needed to make a train of bursts in a HFT series is 4 HFT bursts.
b. The minimum frequency of the EMG bursts in a HFT is 0.3 Hz.
c. The maximum frequency of the EMG bursts in a HFT is 4.0 Hz.

Note 1. The usual range for duration of hypnagogic foot tremor is 250-1000 msec.

Note 2. HFT may simply be a benign movement phenomenon associated with characteristic EMG patterns as there have been no reported clinical consequences.

## Scoring Excessive Fragmentary Myoclonus (EFM)

### 1. The following define EFM:N1,N2,N3

a. The usual maximum EMG burst duration seen in fragmentary myoclonus is 150 msec.
b. At least 20 minutes of NREM sleep with EFM must be recorded.
c. At least 5 EMG potentials per minute must be recorded.

Note 1. EFM may be a benign movement phenomenon associated with a characteristic EMG pattern as there have been no reported clinical consequences.

Note 2. In many cases no visible movements are present. Gross, jerk-like movements across the joint spaces are not observed. When minor movement across a joint space is present, the movement resembles the small twitch-like movements of the fingers, toes, and the corner of the mouth intermittently seen in REM sleep in normal individuals.

Note 3. In some cases when visible movement is present, the EMG burst duration may be >150 msec.

## Scoring Bruxism

### 1. The following define bruxism:N1,N2

a. Bruxism may consist of brief (phasic) or sustained (tonic) elevations of chin EMG activity that are at least twice the amplitude of background EMG.
b. Brief elevations of chin EMG activity are scored as bruxism if they are 0.25-2 seconds in duration and if at least 3 such elevations occur in a regular sequence.
c. Sustained elevations of chin EMG activity are scored as bruxism if the duration is more than 2 seconds.
d. A period of at least 3 seconds of stable background chin EMG must occur before a new episode of bruxism can be scored.
e. Bruxism can be scored reliably by audio in combination with polysomnography by a minimum of 2 audible tooth grinding episodes per night of polysomnography in the absence of epilepsy.

Note 1. In sleep, jaw contraction frequently occurs. This contraction can take 2 forms: a) sustained (tonic) jaw clenching contractions or b) a series of repetitive brief (phasic) muscle contractions termed rhythmic masticatory muscle activity (RMMA).

Note 2. In addition to the recommended placement of chin EMG electrodes as noted in adult visual rules section IV.C, (http://www.aasmnet.org/scoringmanual/html/CTechnicalSpecificationsforElect.html) additional masseter electrodes may be placed at the discretion of the investigator or clinician.

## Scoring PSG Features of REM Sleep Behavior Disorder (RBD)

### 1. Score in accordance with the following definitions:

Sustained muscle activity (tonic activity) in REM sleep: An epoch of REM sleep with at least 50% of the duration of the epoch having a chin EMG amplitude greater than the minimum amplitude demonstrated in NREM sleep.

Excessive transient muscle activity (phasic activity) in REM sleep: In a 30-second epoch of REM sleep divided into 10 sequential, 3-second mini-epochs, at least 5 (50%) of the mini-epochs contain bursts of transient muscle activity. In RBD, excessive transient muscle activity bursts are 0.1-5.0 seconds in duration and at least 4 times as high in amplitude as the background EMG activity.

### 2. The polysomnographic characteristics of RBD are characterized by EITHER or BOTH of the

following features:N1,N2,N3,N4

a. Sustained muscle activity in REM sleep in the chin EMG
b. Excessive transient muscle activity during REM in the chin or limb EMG

Note 1. Time-synchronized, audio-equipped video PSG demonstrating dream enactment or a characteristic clinical history are necessary to make the diagnosis of RBD in addition to polysomnographic evidence of REM sleep without atonia or excessive transient muscle activity in REM sleep.

Note 2. Transient muscle activity and occasional accompanying visible twitching of small muscle groups are a normal phenomenon seen in REM sleep (see adult visual rules section IV.I). (http://www.aasmnet.org/scoringmanual/html/IScoringStageR.html) When larger muscle groups are involved, this activity is not associated with large, overt muscular activity acting across large joints. When smaller muscle groups are involved, the movement often involves the distal muscles of the hands and face or the corners of the mouth. Transient muscle activity may be excessive in RBD.

Note 3. The sustained muscle activity or the excessive transient muscle activity observed in REM sleep may be interrupted by superimposed (usually dream-enacting) behaviors of RBD.

Note 4. In normal individuals there is an atonia seen in REM sleep in the chin and anterior tibialis EMG. In this state the baseline amplitude of the EMG signal decreases markedly. This atonia of REM sleep is lost to a considerable extent in RBD, with variable frequency, and as a result, the EMG baseline amplitude is often higher. In this situation, the EMG can be said to be in a tonic rather than atonic state.

## Scoring the PSG Features of Rhythmic Movement Disorder

### 1. The following define the polysomnographic characteristics of rhythmic movement

disorder:N1,N2

a. The minimum frequency for scoring rhythmic movements is 0.5 Hz.
b. The maximum frequency for scoring rhythmic movements is 2.0 Hz.
c. The minimum number of individual movements required to make a cluster of rhythmic movements is 4 movements.
d. The minimum amplitude of an individual rhythmic burst is 2 times the background EMG activity.

Note 1. Bipolar surface electrodes should be placed to record electrical activity of the large muscle groups involved.

Note 2. Time-synchronized video PSG, in addition to polysomnographic criteria, is necessary to make the diagnosis of rhythmic movement disorder.

## Technical Specifications

1. For identification of an apnea during a diagnostic study, use an oronasal thermal airflow sensor to monitor airflow.N1
2. For identification of an apnea during a diagnostic study when the oronasal thermal airflow sensor is not functioning or the signal is not reliable, use one of the following (alternative apnea sensors):N2
a. nasal pressure transducer (with or without square root transformation)
b. RIPsum (calibrated or uncalibrated)
c. RIPflow (calibrated or uncalibrated)
d. PVDFsum
3. For identification of a hypopnea during a diagnostic study, use a nasal pressure transducer (with or without square root transformation of the signal) to monitor airflow.N3
4. For identification of a hypopnea during a diagnostic study when the nasal pressure transducer is not functioning or the signal is not reliable, use one of the following (alternative hypopnea sensors):N2
a. oronasal thermal airflow
b. RIPsum (calibrated or uncalibrated)
c. RIPflow (calibrated or uncalibrated)
d. dual thoracoabdominal RIP belts (calibrated or uncalibrated)
e. PVDFsum
5. During positive airway pressure (PAP) titration, use the PAP device flow signal to identify apneas or hypopneas.

### 6. For monitoring respiratory effort, use one of the following:

a. esophageal manometry
b. dual thoracoabdominal RIP belts (calibrated or uncalibrated)
c. dual thoracoabdominal PVDF belts

### 7. For monitoring oxygen saturation, use pulse oximetry with a maximum acceptable signal

averaging time of ≤3 seconds at a heart rate of 80 beats per minute.

8. For monitoring snoring, use an acoustic sensor (e.g. microphone), piezoelectric sensor or nasal pressure transducer.N4

9. For detection of hypoventilation during a diagnostic study, use arterial PCO2, transcutaneous PCO2 or end-tidal PCO2.N5,N6

### 10. For detection of hypoventilation during PAP titration, use arterial PCO2, or use

transcutaneous PCO2.N5,N6

Note 1. Thermal sensors include thermistors, thermocouples, or polyvinylidene fluoride (PVDF) airflow sensors.

Note 2. RIP stands for respiratory inductance plethysmography. The RIPsum is the sum of the signals from thoracic and abdominal RIP sensors (belts) and excursions in the signal are an estimate of tidal volume. The RIPflow is the time derivative of the RIPsum and excursions in the signal are an estimate of airflow. The PVDFsum is the sum of signals from thoracic and abdominal PVDF sensors (belts). Recording of RIPsum, RIPflow, or PVDFsum is optional.

Note 3. Using the nasal pressure signal without square root transformation for scoring hypopneas will result in a slightly higher hypopnea index than scoring using a square root transformation of the signal. This difference is not clinically significant in most patients.

Note 4. Monitoring snoring is optional as noted in Parameters to be Reported II.F. (http://www.aasmnet.org/scoringmanual/html/FRespiratoryEvents.html)

Note 5. Monitoring hypoventilation is optional as noted in Parameters to be Reported II.F. (http://www.aasmnet.org/scoringmanual/html/FRespiratoryEvents.html)

Note 6. a.Clinical judgment is essential when assessing the accuracy of end-tidal PCO2 and transcutaneous PCO2 readings. The values should not be assumed to be accurate surrogates of the arterial PCO2 when the values do not fit the clinical picture.

b. The transcutaneous PCO2 sensor should be calibrated with a reference gas according to the manufacturer’s recommendations and when the accuracy of the reading is doubtful. Of note, the value of the transcutaneous PCO2 typically lags behind changes in the arterial PCO2 by two minutes or more.
c. The end-tidal PCO2 often malfunctions or provides falsely low values in patients who have marked nasal obstruction, profuse nasal secretions, are obligate mouth breathers, or who are receiving supplemental oxygen It is crucial to obtain a plateau in the end-tidal waveform for the signal to be considered valid.

## Measuring Event Duration

1. For scoring either an apnea or a hypopnea, the event duration is measured from the nadir preceding the first breath that is clearly reduced to the beginning of the first breath that approximates the baseline breathing amplitude. (see red bracket, Figures 1 and 2)
2. For apnea duration, the oronasal thermal sensor signal (diagnostic study) or PAP device flow signal (PAP titration study) should be used to determine the event duration. For hypopnea event duration, the nasal pressure signal (diagnostic study) or PAP device flow signal (PAP titration study) should be utilized. When the diagnostic study sensors fail or are inaccurate, alternative sensors may be used. (see Technical Specifications for adults A.2 and A.4) (http://www.aasmnet.org/scoringmanual/html/ATechnicalSpecifications1.html)

### 3. When baseline breathing amplitude cannot be easily determined (and when underlying

breathing variability is large), events can also be terminated when either there is a clear and sustained increase in breathing amplitude, or in the case where a desaturation has occurred, there is event-associated resaturation of at least 2%.

## Scoring of Apneas

### 1. Score a respiratory event as an apnea when BOTH of the following criteria are

met:N1,N2,N3,N4 (see Figure 1)

a. There is a drop in the peak signal excursion by ≥90% of pre-event baseline using an oronasal thermal sensor (diagnostic study), PAP device flow (titration study) or an alternative apnea sensor (diagnostic study).
b. The duration of the ≥90% drop in sensor signal is ≥10 seconds.
2. Score an apnea as obstructive if it meets apnea criteria and is associated with continued or increased inspiratory effort throughout the entire period of absent airflow.
3. Score an apnea as central if it meets apnea criteria and is associated with absent inspiratory effort throughout the entire period of absent airflow.
4. Score an apnea as mixed if it meets apnea criteria and is associated with absent inspiratory effort in the initial portion of the event, followed by resumption of inspiratory effort in the second portion of the event.N5

Note 1. Identification of an apnea does not require a minimum desaturation criterion.

Note 2. If a portion of a respiratory event that would otherwise meet criteria for a hypopnea meets criteria for apnea, the entire event should be scored as an apnea.

Note 3. If the apnea or hypopnea event begins or ends during an epoch that is scored as sleep, then the corresponding respiratory event can be scored and included in the computation of the apnea hypopnea index (AHI). This situation usually occurs when an individual has a high AHI with events occurring so frequently that sleep is severely disrupted and epochs may end up being scored as wake even though <15 seconds of sleep is present during the epoch containing that portion of the respiratory event. However, if the apnea or hypopnea occurs entirely during an epoch scored as wake, it should not be scored or counted towards the apnea hypopnea index because of the difficulty of defining a denominator in this situation. If these occurrences are a prominent feature of the polysomnogram and/or interfere with sleep onset, their presence should be mentioned in the narrative summary of the study.

Note 4. For alternative apnea sensors see T (http://www.aasmnet.org/scoringmanual/html/ATechnicalSpecifications1.html)echnical Specifications for adults A.2. (http://www.aasmnet.org/scoringmanual/html/ATechnicalSpecifications1.html)

Note 5. There is not sufficient evidence to support a specific duration of the central and obstructive components of a mixed apnea; thus, specific durations of these components are not recommended.

## Scoring of Hypopneas

Scoring hypopneas as central or obstructive events is optional as noted in Parameters to be Reported II.F. (http://www.aasmnet.org/scoringmanual/html/FRespiratoryEvents.html)

1. Score a respiratory event as a hypopnea if ALL of the following criteria are met:N1,N2,N3 (see Figure 2)
a. The peak signal excursions drop by ≥30% of pre-event baseline using nasal pressure (diagnostic study), PAP device flow (titration study), or an alternative hypopnea sensor (diagnostic study).
b. The duration of the ≥30% drop in signal excursion is ≥10 seconds.
c. There is a ≥3% oxygen desaturation from pre-event baseline or the event is associated with an arousal.
2. If electing to score obstructive hypopneas, score a hypopnea as obstructive if ANY of the following criteria are met:
a. Snoring during the event
b. Increased inspiratory flattening of the nasal pressure or PAP device flow signal compared to baseline breathing
c. Associated thoracoabdominal paradox occurs during the event but not during pre-event breathing
3. If electing to score central hypopneas, score a hypopnea as central if NONE of the following criteria are met:
a. Snoring during the event
b. Increased inspiratory flattening of the nasal pressure or PAP device flow signal compared to baseline breathing
c. Associated thoracoabdominal paradox occurs during the event but not during pre-event breathing

Note 1. If necessary, the number of hypopneas using a definition requiring a ≥30% drop in flow for ≥10 seconds that is associated with ≥4% desaturation may additionally be reported to qualify a patient for PAP reimbursement (eg. Medicaid or Medicare patients).

Note 2. For alternative hypopnea sensors see Technical Specifications for adults A.4. (http://www.aasmnet.org/scoringmanual/html/ATechnicalSpecifications1.html)

Note 3. Supplemental oxygen may blunt desaturation. There are currently no scoring guidelines for when a patient is on supplemental oxygen and no desaturation is noted. If the diagnostic study is performed while the subject is on supplemental oxygen, its presence should be mentioned in the narrative summary of the study.

## Scoring Respiratory Effort-Related Arousal

Scoring respiratory effort-related arousals is optional as noted in Parameters to be Reported II.F. (http://www.aasmnet.org/scoringmanual/html/FRespiratoryEvents.html)

1. If electing to score respiratory effort-related arousals, score a respiratory event as a respiratory effort-related arousal (RERA) if there is a sequence of breaths lasting ≥10 seconds characterized by increasing respiratory effort or by flattening of the inspiratory portion of the nasal pressure (diagnostic study) or PAP device flow (titration study) waveform leading to arousal from sleep when the sequence of breaths does not meet criteria for an apnea or hypopnea. (see Figure 3)

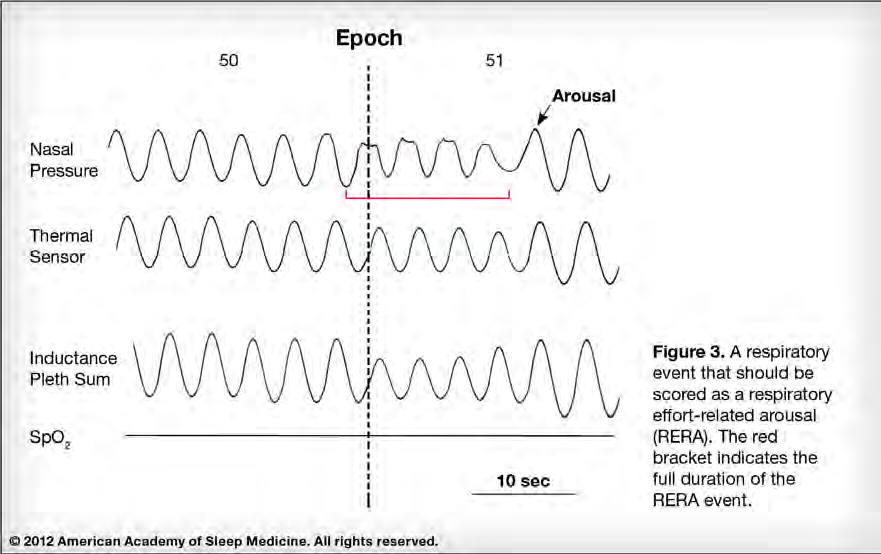
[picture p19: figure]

## Scoring Hypoventilation

Monitoring hypoventilation is optional as noted in Parameters to be Reported II.F. (http://www.aasmnet.org/scoringmanual/html/FRespiratoryEvents.html)

1. If electing to score hypoventilation, score a respiratory event as hypoventilation during sleep if EITHER of the below occur:N1
a. There is an increase in the arterial PCO2 (or surrogate) to a value >55 mmHg for ≥10 minutes.
b. There is ≥10 mmHg increase in arterial PCO2 (or surrogate) during sleep (in comparison to an awake supine value) to a value exceeding 50 mmHg for ≥10 minutes.

Note 1. See Technical Specifications for adults A.9 and A.10 (http://www.aasmnet.org/scoringmanual/html/ATechnicalSpecifications1.html) for information on surrogate signals for monitoring hypoventilation.

## Scoring Cheyne-Stokes Breathing

1. Score a respiratory event as Cheyne-Stokes breathing if BOTH of the following are met: (see Figure 4)N1,N2
a. There are episodes of ≥3 consecutive central apneas and/or central hypopneas separated by a crescendo and decrescendo change in breathing amplitude with a cycle length of ≥40 seconds.
b. There are ≥5 central apneas and/or central hypopneas per hour of sleep associated with the crescendo/decrescendo breathing pattern recorded over ≥2 hours of monitoring.

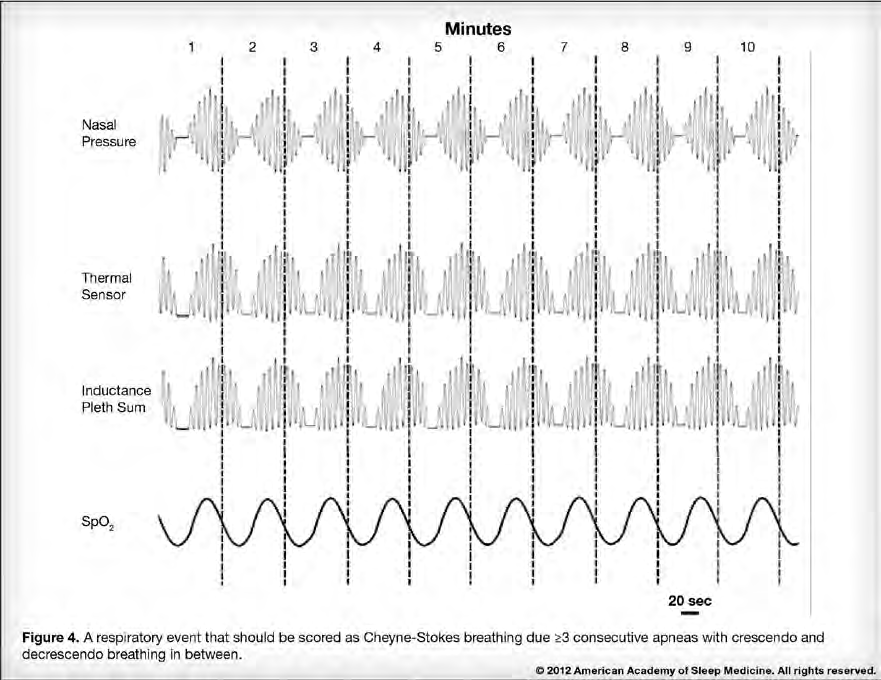
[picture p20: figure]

Note 1. Cycle length is the time from the beginning of a central apnea to the end of the next crescendo-decrescendo respiratory phase (start of the next apnea).

Note 2. Central apneas that occur within a run of Cheyne-Stokes breathing should be scored as individual apneas as well.

# Glossary of Terms

Apnea: Cessation of airflow (≥90% decrease in apnea sensor excursions compared to baseline) of a minimum duration as defined by adult (VIII.C.1) (http://www.aasmnet.org/scoringmanual/html/CScoringofApneas.html) and pediatric rules (VIII.D.1). (http://www.aasmnet.org/scoringmanual/html/DScoringofApneas.html) Apneas are classified as obstructive, mixed, or central based on the pattern of respiratory effort.

Alpha rhythm: An EEG pattern consisting of trains of sinusoidal 8-13 Hz activity recorded over the occipital region with eye closure and attenuating with eye opening.

Asystole: An interruption of cardiac rhythm lasting more than 3 seconds.

Atrial fibrillation: An irregularly irregular ventricular rhythm associated with replacement of consistent P waves by rapid electrical oscillations.

Beta rhythm: An EEG rhythm consisting of 13-30 Hz activity.

Bradycardia (during sleep): A sustained (>30 seconds) heart rate less than 40 beats per minute for ages 6 years through adulthood.

Bruxism: Grinding or clenching of the teeth during sleep that is often associated with arousal. (Scoring rule VII.E.1) (http://www.aasmnet.org/scoringmanual/html/EScoringBruxism.html)

Central hypopnea: A specified reduction in airflow lasting at least 10 seconds in adults or the equivalent of 2 breaths in children during which there is no evidence of snoring, increased inspiratory flattening of the nasal pressure or PAP device flow signal compared to baseline breathing, or associated thoracoabdominal paradox.

Cheyne-Stokes breathing: A breathing rhythm with a specified crescendo and decrescendo change in breathing amplitude separating central apneas or hypopneas. (Scoring rule for adults VIII.G.1) (http://www.aasmnet.org/scoringmanual/html/GScoringCheyneStokesBreathing.html)

Delta frequency: An EEG rhythm consisting of 0-4 Hz activity. (See definition of slow wave activity.)

Derivation: The recorded voltage difference between two electrodes (e.g. EEG, EOG, chin EMG derivations).

Dominant posterior rhythm: An EEG pattern with frequency appropriate to age which is observed over the occipital regions during relaxed wakefulness with eyes closed and attenuates with eye opening or attention.

Excessive fragmentary myoclonus: Limb EMG activity of a specified frequency and duration often unassociated with visible movement. This polysomnographic finding is not thought to have physiological significance.

Eye blinks: EOG events consisting of conjugate vertical eye movements at a frequency of 0.5-2 Hz present in wakefulness with the eyes open or closed.

Hypnagogic foot tremor: Trains of EMG activity of the lower limb with a specified frequency; not a defined disorder.

Hypnagogic hypersynchrony: An EEG pattern consisting of paroxysmal runs or bursts of diffuse high amplitude sinusoidal 75 to 350 μV, 3-4.5 Hz waves which begin abruptly, are usually widely distributed but often maximal over the central, frontal, or frontocentral scalp regions.

Hypopnea: A reduction in airflow with the minimum amplitude and duration as specified in the hypopnea rules for adults (VIII.D.1) (http://www.aasmnet.org/scoringmanual/html/DScoringofHypopneas.html) and children (VIII.E.1). (http://www.aasmnet.org/scoringmanual/html/EScoringofHypopneas.html) The reduction in airflow must be accompanied by a ≥3% desaturation or an arousal.

Hypoventilation: A specified period of increased PCO2 of >50 mm Hg in children or >55 mg Hg in adults, or a rise of PCO2 during sleep of ≥10 mm Hg that exceeds 50 mm Hg for a specified period of time in adults.

K complex: An EEG event consisting of a well delineated negative sharp wave immediately followed by a positive component standing out from the background EEG with total duration ≥0.5 seconds, usually maximal in amplitude over the frontal regions.

Low-amplitude, mixed-frequency activity: An EEG pattern consisting of low amplitude, predominantly 4-7 Hz activity.

Low chin EMG tone: Baseline EMG activity in the chin derivation no higher than in any other sleep stage and usually at the lowest level of the entire recording.

Major body movement: Movement and muscle artifact obscuring the EEG for more than half an epoch to the extent that the sleep stage cannot be determined.

Narrow complex tachycardia: A cardiac rhythm lasting a minimum of 3 consecutive beats with QRS duration of <120 msec and a rate of >100 per minute.

Nasal pressure transducer: A pressure transducer that measures the pressure (relative to atmospheric pressure) inside the nasal orifice using a nasal cannula. The pressure difference across the nasal inlet during breathing is proportional to the magnitude of airflow squared. A square root transformation of the nasal pressure signal is proportional to airflow. The inspiratory waveform of the nasal pressure signal exhibits a flattened pattern during airflow limitation provided the signal from the transducer is recorded as a DC signal or as an AC signal with an appropriate low filter setting.

Positive airway pressure (PAP) flow: An airflow signal derived from a pressure transducer built in to the PAP device.

Periodic breathing: >3 episodes of central apnea lasting >3 seconds separated by no more than 20 seconds of normal breathing in children.

Periodic limb movements of sleep: Movements of the limbs during sleep occurring with a specified frequency, duration, and amplitude.

PVDF sensor: Polyvinylidene fluoride (PVDF) film is a fluoropolymer substance that reacts to changes in temperature when used as a thermal airflow sensor and to impedance changes when used as an effort sensor.

PVDFsum: PVDFsum is the electrical sum of signals recorded from the thoracic and abdominal PVDF sensors.

Rapid eye movements: Eye movements recorded in the EOG derivations consisting of conjugate, irregular, sharply peaked eye movements with an initial deflection usually lasting <500 msec. Rapid eye movements may be noted during stage W or stage R.

Reading eye movements: Eye movements recorded in the EOG derivations consisting of trains of conjugate eye movements characterized by an initial slow phase followed by a rapid phase in the opposite direction as the subject reads.

REM Sleep Behavior Disorder: A parasomnia characterized by relative atonia during REM and associated with potentially harmful dream-enacting behaviors.

Respiratory effort related arousal: A sequence of breaths characterized by increasing respiratory effort (esophageal manometry); inspiratory flattening in the nasal pressure or PAP device flow channel; or an increase in end-tidal PCO2 (children) leading to an arousal from sleep. Respiratory effort related arousals do not meet criteria for hypopnea and have a minimum duration of ≥10 seconds in adults or the duration of at least two breaths in children.

Respiratory inductance plethysmography (RIP): A technology that uses alternating current in belts surrounding the thorax and abdoment to generate a signal based on changes in the inductance of belts during breathing. The band inductance depends on the cross-sectional area encircled by the band.

Rhythmic Movement Disorder: Repetitive, stereotyped and rhythmic motor behaviors that occur predominantly during drowsiness or sleep and involve large muscle groups.

Rhythmic anterior theta activity: An EEG pattern consisting of runs of 5-7 Hz rhythmic theta activity maximal over the frontal or frontocentral regions.

RIPflow: RIPflow is the time derivative of the RIPsum signal; excursions in the signal are an estimate of airflow.

RIPsum: RIPsum is the electrical sum of the signals from the thoracic and abdominal RIP sensors; excursions in the signal are an estimate of tidal volume.

Sawtooth waves: An EEG pattern consisting of trains of sharply contoured or triangular, often serrated, 2-6 Hz waves maximal in amplitude over the central head regions and often, but not always, preceding a burst of rapid eye movements.

Sleep onset: The start of the first epoch scored as any stage other than stage W.

Sleep spindle: An EEG event consisting of a train of distinct waves with frequency 11-16 Hz (most commonly 12-14 Hz) with a duration ≥0.5 seconds, usually maximal in amplitude over the central regions.

Slow eye movements: EOG events consisting of conjugate, reasonably regular, sinusoidal eye movements with an initial deflection usually lasting >500 msec. Slow eye movements may be present during drowsy wakefulness or stage N1.

Slow wave activity: Waves measured over the frontal regions with a frequency of 0.5-2 Hz and a peak-to-peak amplitude >75 μV.

Tachycardia or sinus tachycardia (during sleep): A sustained (>30 seconds) sinus heart rate >90 beats per minute for adults.

Thermal sensor: A thermally sensitive device that detects changes in nasal and/or oral airflow based on changes in temperature; thermal sensors include thermistors, thermocouples, or polyvinylidene fluoride (PVDF) airflow sensors.

Theta rhythm: An EEG rhythm consisting of 4-7 Hz activity.

Transient muscle activity: Short irregular bursts of EMG activity usually with duration <0.25 seconds superimposed on low EMG tone. The activity may be seen in the chin or anterior tibial EMG derivations, as well as in EEG or EOG deviations, the latter indicating activity of cranial nerve innervated muscles. The activity is maximal in association with rapid eye movements.

Vertex sharp waves (V waves): An EEG pattern consisting of sharply contoured waves with duration <0.5 seconds maximal over the central region and distinguishable from the background activity.

Wide complex tachycardia: A cardiac rhythm lasting a minimum of 3 consecutive beats with QRS duration ≥120 msec and a rate of >100 per minute.

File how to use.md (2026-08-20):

1. Run `src_python\install.bat` (or an equivalent for Linux)
2. Run command `python .\src_python\read_log.py -f ".\examples\07 July 2026\biometric_2026-07-08_01-57-52.edf" -c --threshold 3 --skip 2 --ignore_last 2`
(or use another .edf file of interest)
This generates the output .html, and start the web server and browser to show the chart

All generated output — the `.zarr` working store and its `_meta.json` / `events.json`
sidecars — is written to **`data_scratchpad/`**, not the repo root. That folder is
gitignored: `meta.json` can carry a `subject.pii` block, so nothing under it should ever
be committed. Override the location with `--out-dir` if you need to.

Notes on the arguments (see `src_python/read_log.py`):
- `-f` takes an EDF+ recording (`.edf`)
- `--skip` / `--ignore_last` are seconds, not sample counts (the EDF's channels run at different native rates — 50 Hz accel vs 1 Hz RR — so a sample count is ambiguous).
- `--threshold` is an accelerometer amplitude threshold in **mg** (physical units read from the EDF+)

3. If the read_log.py runs successfully, it will show the next suggested command, to render the results locally, for example:

`python src_python/serve.py --meta data_scratchpad/biometric_2026-07-09_18-15-01_meta.json`

With no arguments `serve.py` picks the newest `*_meta.json` in `data_scratchpad/`.

3b. (optional) To use the "Windowed PLMI" card — drag-select a range on a chart to
compute PLMI for just that window — also run the metrics service, in a separate
terminal, from the repo root:

`python src_python/serve_metrics.py`

This starts a small API on `http://localhost:8800` (the default `src_web/metrics-config.js`
points at) and reads recordings from `data_scratchpad/` (override with
`--recordings-root`). The chart works fine without it — you'll just see "metrics service
unavailable" in that card instead of a value if it isn't running.

4. (only if required) run npm build:
```
cd src_web
npm.cmd run build
```

5. Then to deploy to a netlify server, run

`python src_python/deploy.py`

 or deploy a specific data set with 

`python src_python/deploy.py --zarr data_scratchpad/<recording>.zarr --meta data_scratchpad/<recording>_meta.json`

For that to work, make sure you have a correct `netlify.json` in the scr_python folder which looks like:

```
{
  "site_id": "b2f98b73-xxxx-xxxx-xxxx-6f6d0a3f8xxxxx",
  "token": "xxx_t1gKKx3RjxxxxxxxxxxxxxUGsYPL7xxxxx"
}
```

Each deploy **adds** the study to the site rather than replacing it — the site's
root page lists every study that has been deployed so far, linking to each
one. The viewer (`index.html`) and chart bundle are shared across all studies
and only re-uploaded when their bytes actually change, so deploying a new
study is cheap regardless of how many studies are already live.

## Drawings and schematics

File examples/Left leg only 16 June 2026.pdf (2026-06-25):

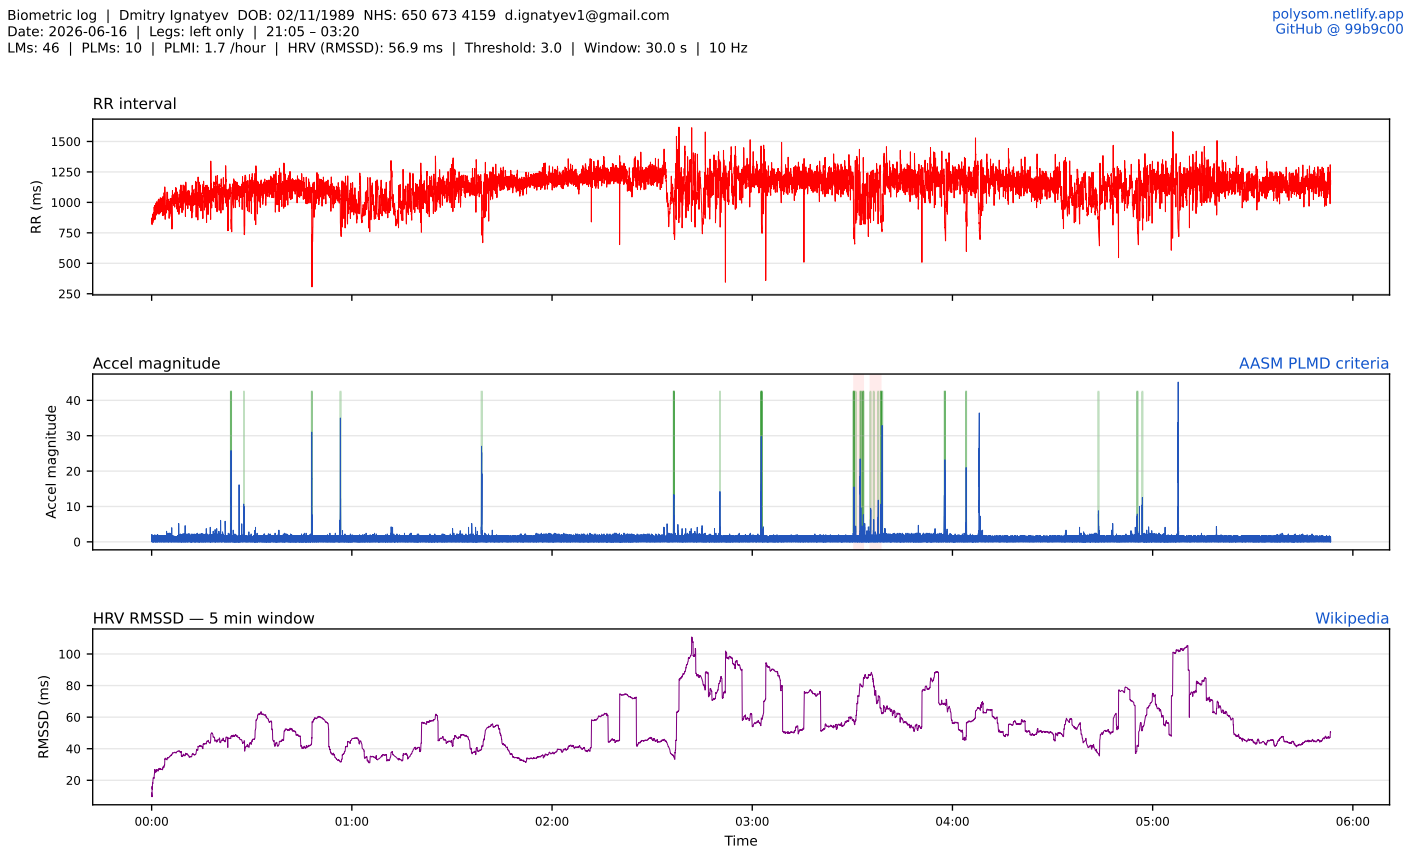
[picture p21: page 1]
RR interval; Accel magnitude; AASM PLMD criteria; Time; RMSSD (ms); HRV RMSSD — 5 min window; Wikipedia

Biometric log | Dmitry Ignatyev DOB: 02/11/1989 NHS: 650 673 4159 d.ignatyev1@gmail.com
Date: 2026-06-16 | Legs: left only | 21:05 – 03:20
LMs: 46 | PLMs: 10 | PLMI: 1.7 /hour | HRV (RMSSD): 56.9 ms | Threshold: 3.0 | Window: 30.0 s | 10 Hz

polysom.netlify.app
GitHub @ 99b9c00 (https://github.com/sunrise-designs/ProtoSom)

### Raw accelerometer channels

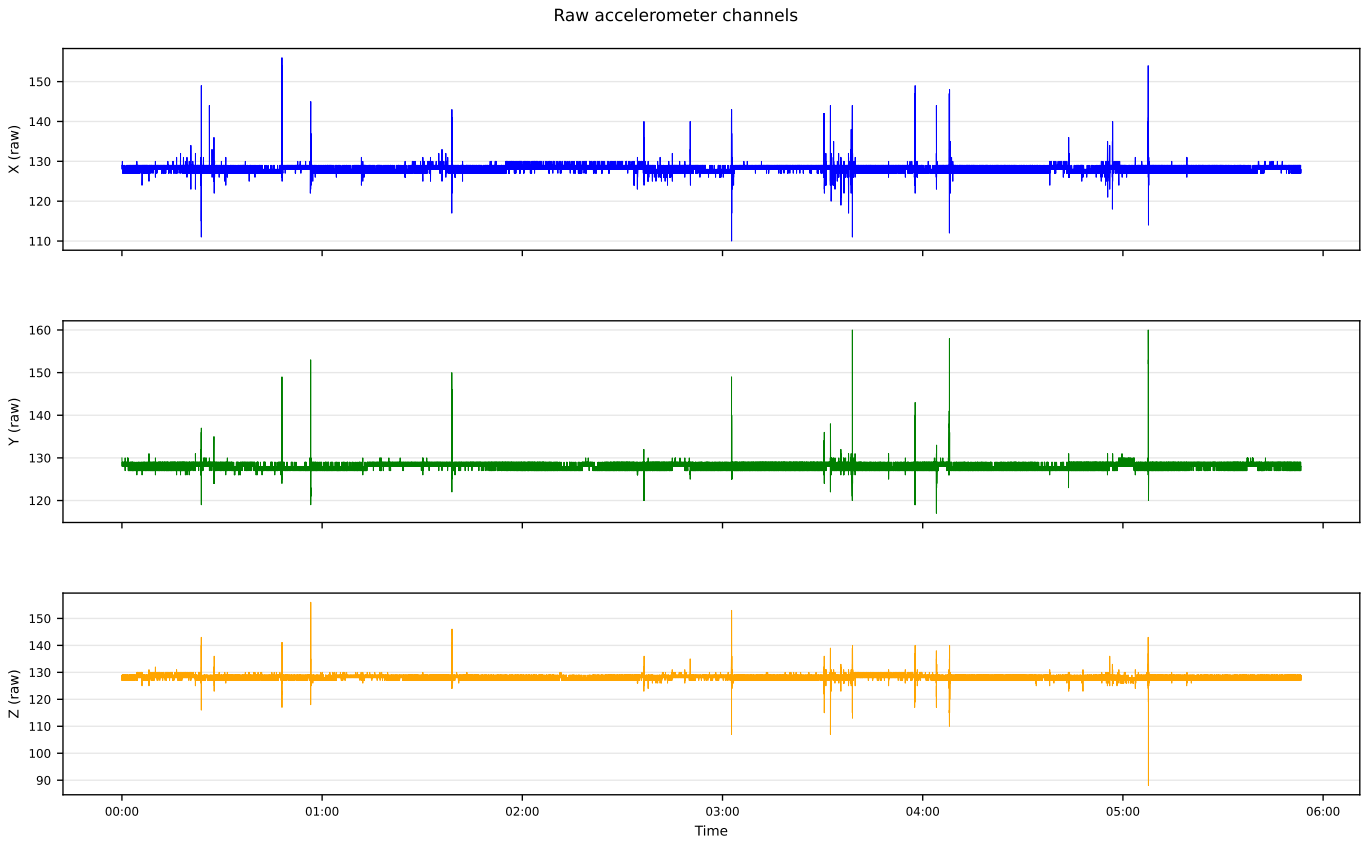
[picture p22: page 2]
X (raw); Y (raw); Time; Z (raw)

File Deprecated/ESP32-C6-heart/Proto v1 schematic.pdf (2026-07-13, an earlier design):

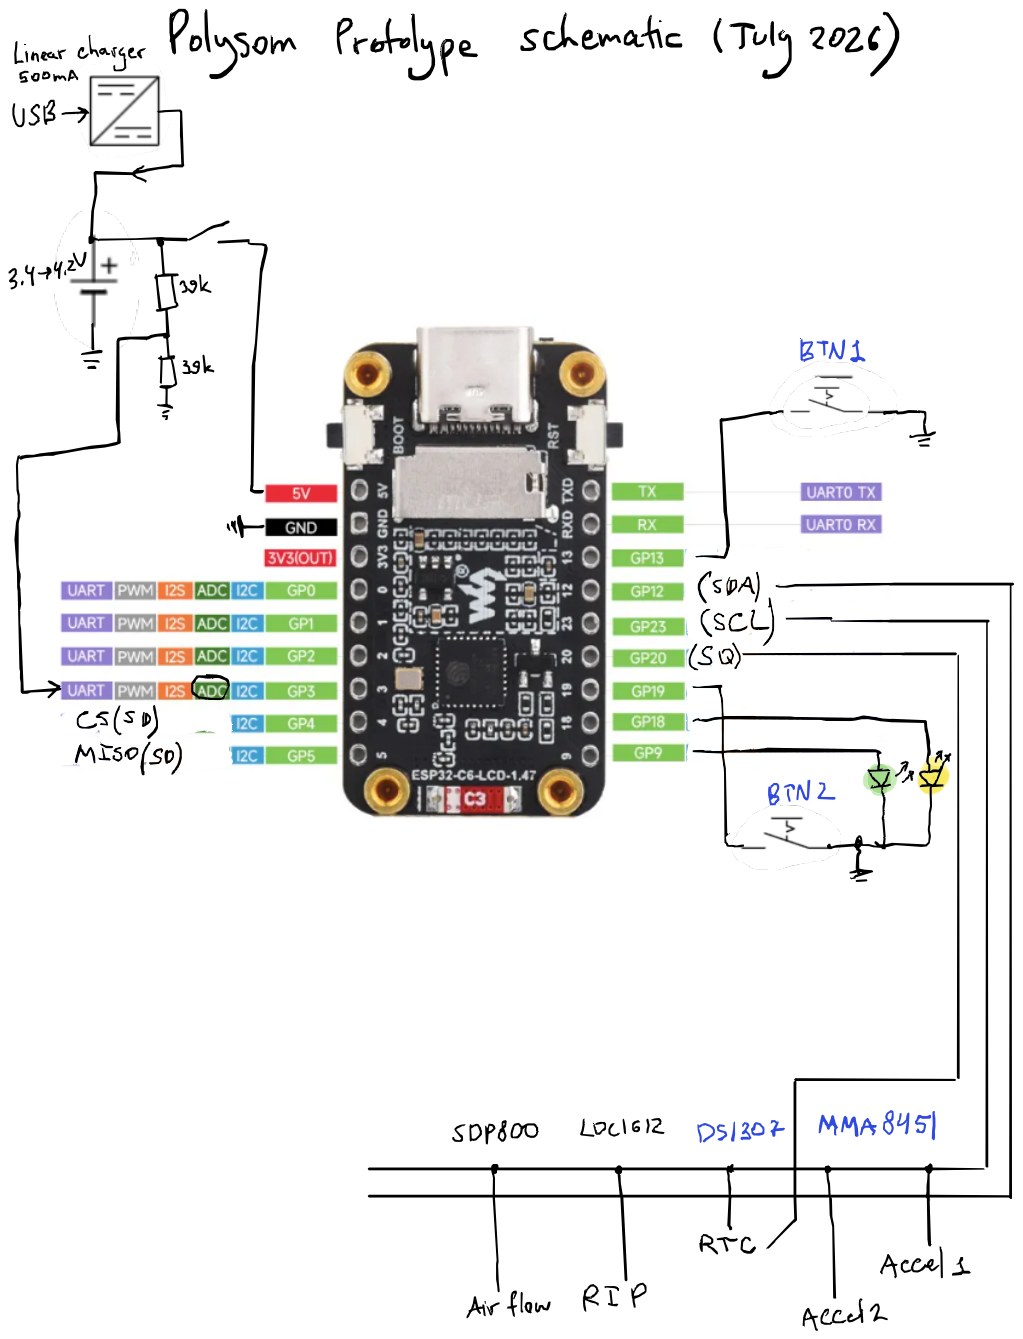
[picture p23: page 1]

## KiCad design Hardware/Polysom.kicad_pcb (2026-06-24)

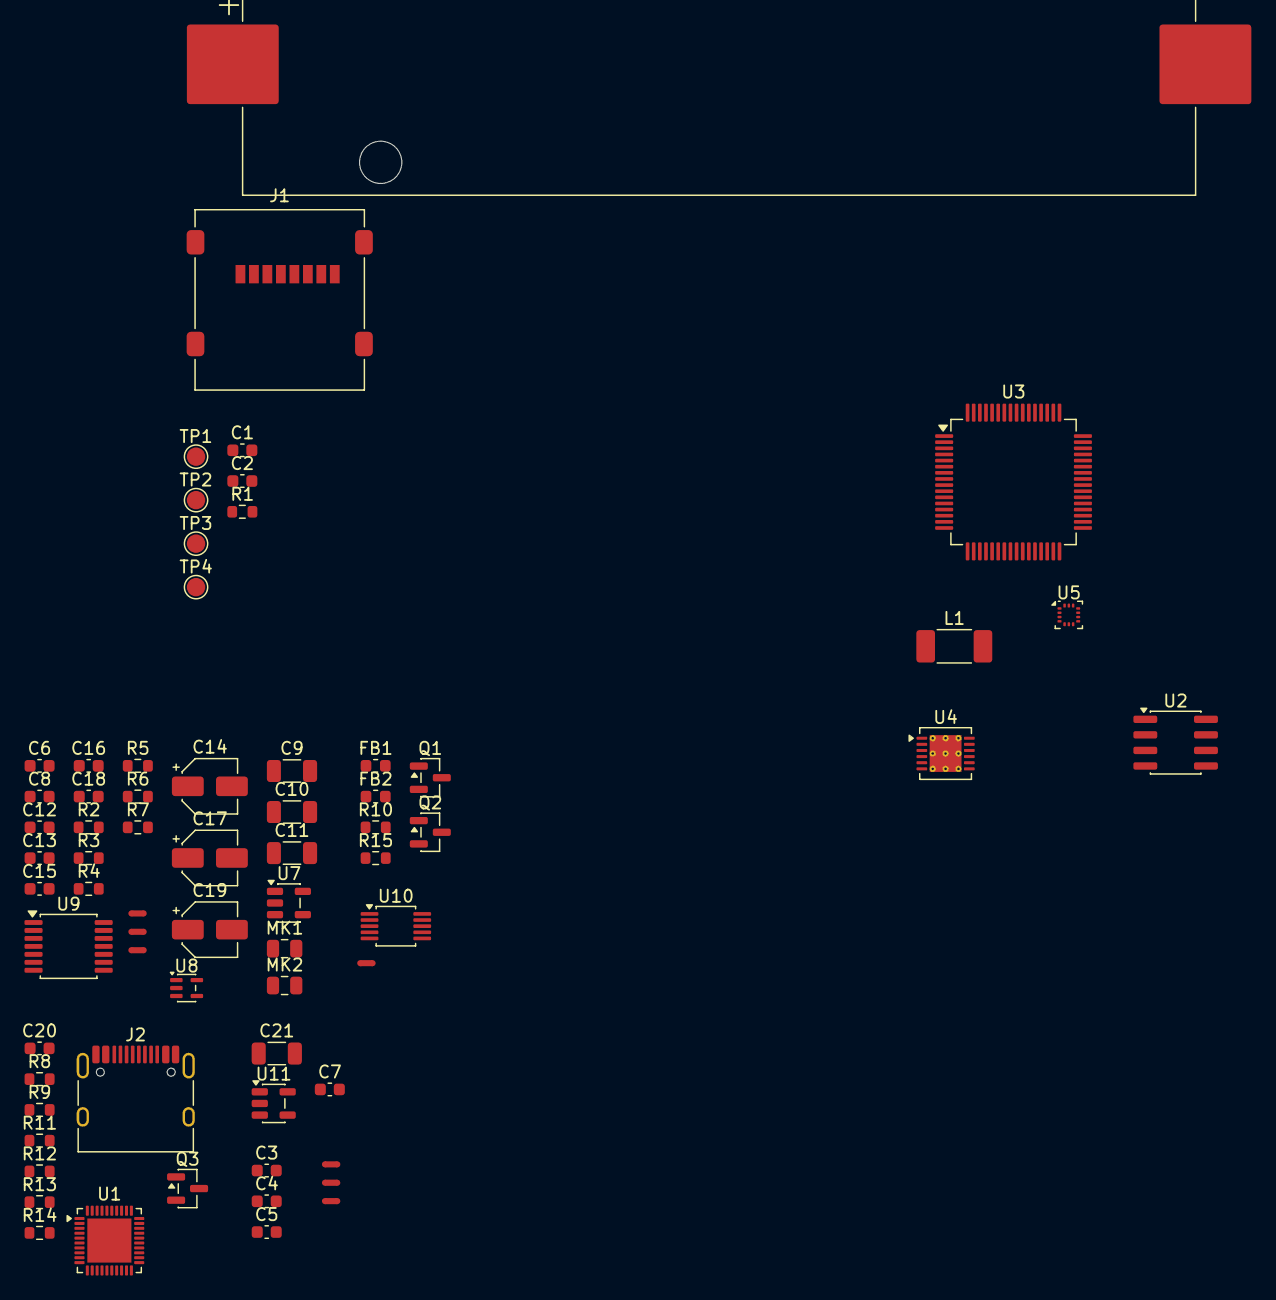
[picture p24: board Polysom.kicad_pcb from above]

Board: 2 copper layers, 68 parts (0 on the bottom side), 42 nets, no tracks yet.

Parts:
BT1: 18650; BatteryHolder_Keystone_1042_1x18650
C1, C2, C12, C13: C; C_0603_1608Metric
C3, C4, C8, C15, C16, C18, C20: 100n; C_0603_1608Metric
C5: 10u; C_0603_1608Metric
C6, C7: 470p; C_0603_1608Metric
C9, C10, C11, C21: 1u; C_1206_3216Metric
C14, C17, C19: 10u; CP_Elec_4x5.4
FB1, FB2: FerriteBead; L_0603_1608Metric
J1: Micro_SD_Card 693072010801; microSD_HC_Molex_47219-2001
J2: USB_C_Receptacle; USB_C_Receptacle_HRO_TYPE-C-31-M-12
L1: L_Chest; L_2010_5025Metric_Pad1.52x2.65mm_HandSolder
MK1, MK2: AOM-5024L-HD-F-R; C_0805_2012Metric
NT1, NT2, NT3, NT4, NT5, NT6, NT7: NetTie_2; NetTie-2_SMD_Pad0.5mm
Q1, Q2, Q3: 2N7002; SOT-23
R1, R8, R9, R10, R13, R14: 10k; R_0603_1608Metric
R2, R3: 1G; R_0603_1608Metric
R4, R5, R6, R7, R15: 100; R_0603_1608Metric
R11, R12: 4K7; R_0603_1608Metric
TP1, TP2, TP3, TP4: TestPoint; TestPoint_Pad_D1.5mm
U1: ESP32-C6; QFN-40-1EP_5x5mm_P0.4mm_EP3.6x3.6mm
U2: OPA1642AID; SOIC-8_3.9x4.9mm_P1.27mm
U3: ADS1299; TQFP-64_10x10mm_P0.5mm
U4: LDC1612; WSON-12-1EP_4x4mm_P0.5mm_EP2.6x3mm_ThermalVias
U5: LIS2DH12TR; LGA-14_2x2mm_P0.35mm_LayoutBorder3x4y
U7, U11: MIC5205-3.3YM5; SOT-23-5
U8: TLV9001IDCK; SOT-353_SC-70-5
U9: PCM1808PWR; TSSOP-14_4.4x5mm_P0.65mm
U10: ADS1115IDGS; TSSOP-10_3x3mm_P0.5mm

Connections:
+3V3: C3.1, C4.1, C5.1, FB1.1, NT5.1 (1_1), R1.2, R10.1, U4.7 (VDD), U5.7 (Vdd_IO), U5.8 (Vdd)
/Accelerometer/SCL: U4.1 (SCL), U5.1 (SCL/SPC), U10.10 (SCL)
/Accelerometer/SDA: U4.2 (SDA), U5.2 (SDA/SDI), U10.9 (SDA)
/EEG/AVDD: U3.19 (AVDD), U3.21 (AVDD), U3.22 (AVDD), U3.54 (AVDD1), U3.56 (AVDD), U3.59 (AVDD), U11.5 (OUT)
/ESP-C6/3V3: C20.1, FB1.2, J1.4 (VDD), R8.1, R9.1, R11.1, R12.1
/ESP-C6/D+: J2.A6 (D+), J2.B6 (D+)
/ESP-C6/D-: J2.A7 (D-), J2.B7 (D-)
/ESP-C6/DAT1: J1.8 (DAT1), R9.2
/ESP-C6/DAT2: J1.1 (DAT2), R8.2
/ESP-C6/VBAT: BT1.1 (+), FB2.2, R13.2
/Microphone/+V: C8.1, C10.1, C16.1, C17.1, U2.8 (V+), U7.5 (OUT), U8.5 (V+), U9.3 (VCC)
/Microphone/VDD: C18.1, C19.1, U9.4 (VDD)
/Microphone/VREF: C14.1, C15.1, U8.1 (+), U9.1 (VREF)
/Microphone/V_GND: C11.1, MK1.1 (-), MK2.1 (-), R2.2, R3.2, U8.3 (-), U8.4
/PERIPH_EN: Q1.1 (G), Q2.3 (D), R15.2, U7.3 (EN), U11.3 (EN)
/RIP/IN0A: C1.1, L1.1, TP1.1 (1_1), U4.9 (IN0A)
/RIP/IN0B: C1.2, L1.2, TP2.1 (1_1), U4.10 (IN0B)
/RIP/IN1A: C2.1, TP3.1 (1_1), U4.11 (IN1A)
/RIP/IN1B: C2.2, TP4.1 (1_1), U4.12 (IN1B)
/SHDN: Q1.3 (D), R10.2, U4.6 (SD)
GND: BT1.2 (-), C3.2, C4.2, C5.2, C6.2, C7.2, C8.2, C9.2, C10.2, C11.2, C14.2, C15.2, C16.2, C17.2, C18.2, C19.2, C20.2, C21.2, J1.6 (VSS), J1.SH (SHIELD), NT1.2, NT2.2, NT3.2, NT4.2, NT6.1 (1_1), NT7.1 (1_1), Q1.2 (S), Q2.2 (S), Q3.2 (S), U1.41 (GND), U2.4 (V-), U3.20 (AVSS), U3.23 (AVSS), U3.32 (AVSS), U3.33 (DGND), U3.49 (DGND), U3.51 (DGND), U3.53 (AVSS1), U3.57 (AVSS), U3.58 (AVSS), U4.3 (CLKIN), U4.8 (GND), U4.13 (GND), U5.3 (SDO), U5.9 (GND), U5.10 (GND), U5.11 (GND), U5.12 (GND), U5.13 (GND), U5.14 (GND), U7.2 (GND), U8.2 (V-), U9.2 (AGND), U9.5 (DGND), U10.3 (GND), U11.2 (GND)
unnamed: J2.A1 (GND), J2.A12 (GND), J2.B1 (GND), J2.B12 (GND)
unnamed: J2.A4 (VBUS), J2.A9 (VBUS), J2.B4 (VBUS), J2.B9 (VBUS)
unnamed: MK1.2 (+), R2.1, R4.2
unnamed: MK2.2 (+), R3.1, R6.2
unnamed: Q3.3 (D), R14.2
unnamed: R13.1, R14.1
unnamed: U1.2 (VDDA3P3), U1.3 (VDDA3P3)
unnamed: R4.1, U2.3 (+)
unnamed: C12.2, R5.2, U2.2 (-)
unnamed: R6.1, U2.5 (+)
unnamed: C13.2, R7.2, U2.6 (-)
unnamed: R1.1, U4.4 (ADDR)
unnamed: C6.1, U7.4 (BP)
unnamed: NT3.1, U9.12 (FMT)
unnamed: NT1.1, U9.10 (MD0)
unnamed: NT2.1, U9.11 (MD1)
unnamed: C12.1, R5.1, U2.1, U9.13 (VIN_L)
unnamed: C13.1, R7.1, U2.7, U9.14 (VIN_R)
unnamed: NT4.1, U10.1 (ADDR)
unnamed: C7.1, U11.4 (BP)
VBAT: C9.1, C21.1, FB2.1, U3.48 (DVDD), U3.50 (DVDD), U7.1 (IN), U10.8 (VDD), U11.1 (IN)

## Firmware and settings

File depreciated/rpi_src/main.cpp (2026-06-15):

#include "Seeed_LDC1612.h"
#include "hr_i2c.h"
#include "sdp800.h"
#include "patient.h"

#include <cstdio>
#include <cstdlib>
#include <cstring>
#include <cerrno>
#include <csignal>
#include <ctime>
#include <string>
#include <unistd.h>
extern "C" {
#include "edflib.h"
}

#define LDC1612_MFR_ID   0x5449
#define LDC1612_DEV_ID   0x3055

#define SAMPLE_RATE_HZ          50
#define SAMPLE_INTERVAL_US      (1000000 / SAMPLE_RATE_HZ)   // 20 000 µs
#define FLUSH_INTERVAL_SAMPLES  (SAMPLE_RATE_HZ * 10)        // every 10 s
#define HR_RAW_RATE_HZ          100

// Physical range for EDF: signed deviation from baseline in raw counts
#define EDF_PHYS_MIN  -1000000.0
#define EDF_PHYS_MAX   1000000.0


#ifndef GIT_COMMIT_HASH
#define GIT_COMMIT_HASH "unknown"
#endif
const char *EQUIPMENT = "OpenPolysom v0.1 (" GIT_COMMIT_HASH ")";

struct Sample { double elapsed; u32 ch0; u32 ch1; };

static volatile bool running = true;

static void on_sigint(int) { running = false; }

static void print_sample(const Sample& s) {
    printf("t=%8.2fs  CH0: %-12u  CH1: %-12u\n", s.elapsed, s.ch0, s.ch1);
}

static std::string timestamped_name(const char* ext) {
    char buf[64];
    time_t now = time(nullptr);
    strftime(buf, sizeof(buf), "ldc1612_%Y%m%d_%H%M%S", localtime(&now));
    return std::string(buf) + ext;
}

static void usage(const char* prog) {
    fprintf(stderr,
        "Usage:\n"
        "  %s              print values to stdout (default)\n"
        "  %s edf [file]   save to EDF  (default: ldc1612_YYYYMMDD_HHMMSS.edf)\n",
        prog, prog);
}

static void average_raw_bufs(const u32* ch0_raw_buf, const u32* ch1_raw_buf, u32& ch0_avg, u32& ch1_avg) {
    uint64_t sum0 = 0, sum1 = 0;
    for (int i = 0; i < SAMPLE_RATE_HZ; i++) {
        sum0 += ch0_raw_buf[i];
        sum1 += ch1_raw_buf[i];
    }
    ch0_avg = sum0 / SAMPLE_RATE_HZ;
    ch1_avg = sum1 / SAMPLE_RATE_HZ;
}

int main(int argc, char* argv[]) {
    enum class Mode { PRINT, EDF };

    PatientInfo patient = load_patient("patient.cfg");

    Mode mode = Mode::PRINT;
    std::string out_file;

    if (argc > 1) {
        if (strcmp(argv[1], "edf") == 0) {
            mode = Mode::EDF;
            if (argc > 2) out_file = argv[2];
            else          out_file = timestamped_name(".edf");
        } else {
            usage(argv[0]);
            return 1;
        }
    }

    // ── Sensor init ───────────────────────────────────────────────────────────
    LDC1612 sensor;
    if (sensor.init("/dev/i2c-1") != NO_ERROR) {
        fprintf(stderr, "Failed to open I2C bus\n");
        return 1;
    }
    u16 mfr_id = 0, dev_id = 0;
    sensor.IIC_read_16bit(READ_MANUFACTURER_ID, &mfr_id);
    sensor.IIC_read_16bit(READ_DEVICE_ID,       &dev_id);
    if (mfr_id != LDC1612_MFR_ID) {
        fprintf(stderr, "LDC1612 not found on bus (mfr=0x%04X dev=0x%04X)\n", mfr_id, dev_id);
        return 1;
    }
    sensor.reset_sensor();
    printf("LDC1612 found  mfr=0x%04X  dev=0x%04X\n", mfr_id, dev_id);
    if (sensor.LDC1612_mutiple_channel_config() != NO_ERROR) {
        fprintf(stderr, "Sensor configuration failed\n");
        return 1;
    }

    // ── Mode-specific setup ───────────────────────────────────────────────────
    int edf_hdl = -1;
    Sdp800 sdp800;
    bool sdp_ok = sdp800.begin();
    if (!sdp_ok) {
        fprintf(stderr, "Warning: SDP800 sensor initialization failed. Pressure readings will be disabled.\n");
    }

    HrI2c hrI2c;
    bool hr_i2c_ok = false;
    hr_i2c_ok = hrI2c.start();
    if (!hr_i2c_ok) {
        fprintf(stderr, "Warning: Failed to start I2C HR reader (AD8232); HR_Raw will be zeros\n");
    }

    if (mode == Mode::EDF) {
        edf_hdl = edfopen_file_writeonly(out_file.c_str(), EDFLIB_FILETYPE_EDFPLUS, 6);
        if (edf_hdl < 0) {
            fprintf(stderr, "edfopen_file_writeonly failed (error %d)\n", edf_hdl);
            return 1;
        }
        edf_set_birthdate(edf_hdl, patient.dob_year, patient.dob_month, patient.dob_day);
        edf_set_patientname(edf_hdl, patient.name);
        edf_set_equipment(edf_hdl, EQUIPMENT);
        struct ChannelInfo {
            const char* transducer;
            const char* label;
            int sample_rate;
            int digital_max;
            int digital_min;
            double physical_max;
            double physical_min;
            const char* physical_dim;
        };

        const ChannelInfo channels[] = {
            { "LDC1612 CH0 - thoracic", "Thoracic", SAMPLE_RATE_HZ,  32767, -32768, EDF_PHYS_MAX, EDF_PHYS_MIN, "Inductance (nH)" },
            { "LDC1612 CH1 - abdomen",  "Abdomen",  SAMPLE_RATE_HZ,  32767, -32768, EDF_PHYS_MAX, EDF_PHYS_MIN, "Inductance (nH)" },
            { "HR - Polar H9 via ESP32-S3", "HR",   1,                32767, -32768, 250.0,        0.0,          "BPM" },
            { "RR - Polar H9 via ESP32-S3", "RR",  5,                32767, -32768, 2000.0,       0.0,          "ms" },
            { "Sensirion SDP800-125P", "Flow",     SAMPLE_RATE_HZ,   32767, -32768, 1000.0,       0.0,          "Pressure" },
            { "AD8232",                "HR_Raw",   HR_RAW_RATE_HZ,   4095,  0,      4095.0,       0.0,          "ADC" }
        };

        const int num_channels = sizeof(channels) / sizeof(channels[0]);
        for (int i = 0; i < num_channels; i++) {
            edf_set_transducer(edf_hdl, i, channels[i].transducer);
            edf_set_label(edf_hdl, i, channels[i].label);
            edf_set_samplefrequency(edf_hdl, i, channels[i].sample_rate);
            edf_set_digital_maximum(edf_hdl, i, channels[i].digital_max);
            edf_set_digital_minimum(edf_hdl, i, channels[i].digital_min);
            edf_set_physical_maximum(edf_hdl, i, channels[i].physical_max);
            edf_set_physical_minimum(edf_hdl, i, channels[i].physical_min);
            edf_set_physical_dimension(edf_hdl, i, channels[i].physical_dim);
        }

       

        printf("Recording to %s at %d Hz  HR source: ESP32-S3 I2C  (Ctrl-C to stop)\n\n",
               out_file.c_str(), SAMPLE_RATE_HZ);

    } else {
        printf("%-10s  %-12s  %-12s\n", "Time (s)", "CH0", "CH1");
        printf("----------  ------------  ------------\n");
    }

    // ── Main loop ─────────────────────────────────────────────────────────────
    signal(SIGINT, on_sigint);
    struct timespec t0;
    clock_gettime(CLOCK_MONOTONIC, &t0);

    if (edf_hdl >= 0) {
        time_t start_time = time(nullptr);
        struct tm tm_info;
        localtime_r(&start_time, &tm_info);
        if (edf_set_startdatetime(edf_hdl, tm_info.tm_year + 1900, tm_info.tm_mon + 1, tm_info.tm_mday,
                                  tm_info.tm_hour, tm_info.tm_min, tm_info.tm_sec) < 0) {
            fprintf(stderr, "edf_set_startdatetime failed\n");
        }
    }

    long sample_count = 0;
    long edf_records = 0;
    double ch0_buf[SAMPLE_RATE_HZ], ch1_buf[SAMPLE_RATE_HZ];
    double hr_buf[1] = { 0.0 };
    double rr_buf[5] = { 0.0 };
    double flow_buf[SAMPLE_RATE_HZ] = { 0.0 };
    double hr_raw_buf[HR_RAW_RATE_HZ] = { 0.0 };
    int rr_slot = 0;
    bool offsets_determined = false;
    u32 ch0_raw_buf[SAMPLE_RATE_HZ], ch1_raw_buf[SAMPLE_RATE_HZ];
    u32 ch0_baseline = 0, ch1_baseline = 0;
    int buf_idx = 0;

    while (running) {
        u32 ch0 = 0, ch1 = 0;
        sensor.get_channel_result(CHANNEL_0, &ch0);
        sensor.get_channel_result(CHANNEL_1, &ch1);

        struct timespec now;
        clock_gettime(CLOCK_MONOTONIC, &now);
        double elapsed = (now.tv_sec - t0.tv_sec) + (now.tv_nsec - t0.tv_nsec) * 1e-9;
        Sample s = {elapsed, ch0, ch1};
        sample_count++;

        double sdp_pressure_mbar = 0.0;
        if (sdp_ok) {
            if (!sdp800.readPressureMbar(sdp_pressure_mbar)) {
                fprintf(stdout, "Warning: SDP800 read failed\n");
                sdp_ok = false;
                sdp_pressure_mbar = 0.0;
            }
        }

        if (sample_count % (SAMPLE_RATE_HZ / 5) == 0) {
            int latestHr = 0;
            int latestRr = 0;
            if (hr_i2c_ok && hrI2c.getLatestHR(latestHr, latestRr)) {
                rr_buf[rr_slot] = static_cast<double>(latestRr);
            } else {
                rr_buf[rr_slot] = 0.0;
            }
            rr_slot = (rr_slot + 1) % 5;
        }

        switch (mode) {
            case Mode::PRINT:
                print_sample(s);
                printf("RR: %.1f\n", rr_buf[rr_slot]);
                if (sample_count % SAMPLE_RATE_HZ == 0 && sdp_ok) {
                    printf("SDP800 pressure: %.3f mbar\n", sdp_pressure_mbar);
                }
                break;

            case Mode::EDF: {
                ch0_raw_buf[buf_idx] = ch0;
                ch1_raw_buf[buf_idx] = ch1;
                flow_buf[buf_idx] = sdp_pressure_mbar;

                

                buf_idx++;
                double time_to_recalibrate = 10 * 60; // 10 minutes
                if (elapsed >= time_to_recalibrate && 
                    buf_idx == SAMPLE_RATE_HZ && 
                    !offsets_determined) {
                        average_raw_bufs(ch0_raw_buf, ch1_raw_buf, ch0_baseline, ch1_baseline);
                        printf("Baseline: CH0: %u  CH1: %u\n", ch0_baseline, ch1_baseline);
                        offsets_determined = true;
                        buf_idx = 0;
                        rr_slot = 0;
                    }
                    // Write even if we have not re-calibrated offsets. I'd
                    // rather have some data with baseline drift than no data at all.
                else if (buf_idx == SAMPLE_RATE_HZ) {
                    for (int i = 0; i < SAMPLE_RATE_HZ; i++) {
                        ch0_buf[i] = (double)ch0_raw_buf[i] - (double)ch0_baseline;
                        ch1_buf[i] = (double)ch1_raw_buf[i] - (double)ch1_baseline;
                    }

                    int latestHr = 0;
                    int latestRr = 0;
                    if (hr_i2c_ok && hrI2c.getLatestHR(latestHr, latestRr)) {
                        hr_buf[0] = static_cast<double>(latestHr);
                    } else {
                        hr_buf[0] = 0.0;
                    }
                    if (rr_slot != 0) {
                        double lastValue = rr_buf[(rr_slot + 4) % 5];
                        for (int j = rr_slot; j < 5; j++) {
                            rr_buf[j] = lastValue;
                        }
                    }

                    hrI2c.drain(hr_raw_buf, HR_RAW_RATE_HZ);

                    edfwrite_physical_samples(edf_hdl, ch0_buf);
                    edfwrite_physical_samples(edf_hdl, ch1_buf);
                    edfwrite_physical_samples(edf_hdl, hr_buf);
                    edfwrite_physical_samples(edf_hdl, rr_buf);
                    edfwrite_physical_samples(edf_hdl, flow_buf);
                    edfwrite_physical_samples(edf_hdl, hr_raw_buf);
                    buf_idx = 0;
                    rr_slot = 0;
                    edf_records++;
                    if (sample_count % FLUSH_INTERVAL_SAMPLES == 0) {
                        edfflush_file(edf_hdl, edf_records);
                        printf("t=%8.2fs  CH0: %-12u  CH1: %-12u  [flushed]\n", elapsed, ch0, ch1);
                    } else {
                        print_sample(s);
                    }
                }
                break;
            }
        }

        usleep(SAMPLE_INTERVAL_US);
    }

    // ── Cleanup ───────────────────────────────────────────────────────────────
    if (edf_hdl >= 0) {
        edfclose_file(edf_hdl);
    }

    printf("Done.\n");
    return 0;
}

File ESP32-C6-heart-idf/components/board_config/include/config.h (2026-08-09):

#pragma once
#include "sdkconfig.h"
#include "hal/gpio_types.h"
#include <stdint.h>

// ── I2C ───────────────────────────────────────────────────────────────────────
#define I2C_PORT      I2C_NUM_0
#define I2C_SDA_PIN   GPIO_NUM_22
#define I2C_SCL_PIN   GPIO_NUM_23
#define I2C_FREQ_HZ   100000

// ── MMA8451 accelerometer I2C addresses ──────────────────────────────────────
#define MMA_ADDR_0    0x1C
#define MMA_ADDR_1    0x1D

// ── LDC1612 inductive sensor ──────────────────────────────────────────────────
#define LDC_ADDR      0x2B

// ── SDP800 differential pressure sensor ──────────────────────────────────────
#define SDP800_ADDR   0x25

// ── DS3231 real-time clock ────────────────────────────────────────────────────
#define DS3231_ADDR           0x68
#define RTC_SYNC_INTERVAL_MS  600000

// ── Serial time sync (used when no RTC is fitted / holds no valid time) ─────
#define TIME_SYNC_TIMEOUT_MS  30000

// ── ADC — ECG signal (AD8232, raw, logged for later analysis) ────────────────
// ECG_ADC_UNIT stays as the enum constant; ECG_ADC_CHANNEL is the raw integer
// from Kconfig — callers must cast to adc_channel_t at the call site.
#define ECG_ADC_UNIT    ADC_UNIT_1
#define ECG_ADC_CHANNEL 1

// ── SH1106 OLED (128×64, I2C — shares the sensor I2C bus above) ──────────────
#define OLED_ADDR     0x3C
#define OLED_W        128
#define OLED_H        64

// ── SPI bus (SD card only — the LCD used to share this bus, now I2C above) ──
#define SPI_HOST_ID   SPI2_HOST
#define SPI_MOSI_PIN  GPIO_NUM_18
#define SPI_MISO_PIN  GPIO_NUM_20
#define SPI_CLK_PIN   GPIO_NUM_19

// ── SD card ───────────────────────────────────────────────────────────────────
#define SD_CS_PIN     GPIO_NUM_21
#define SD_SPI_FREQ   20000000

// ── User LED ──────────────────────────────────────────────────────────────────
// Active-high indicator; blinked to confirm a successful serial time sync.
#define USER_LED_PIN  GPIO_NUM_15

// ── Sample rates ──────────────────────────────────────────────────────────────
#define ECG_RATE_HZ        100
#define SENSOR_RATE_HZ     50
#define DISPLAY_RATE_HZ    5
#define LOG_RATE_MS        20
#define DISPLAY_RATE_MS    200

// ── EDF file ──────────────────────────────────────────────────────────────────
// Final path is "/sdcard/biometric_YYYY-MM-DD_HH-MM-SS.edf", timestamped at open time.
#define EDF_FILE_DIR    "/sdcard"
#define EDF_FILE_PREFIX "biometric"

// ── Real-time streaming (components/rt_stream) ───────────────────────────────
// Live sample streaming over Wi-Fi, for watching the signals while a recording
// runs. OFF by default: the radio costs the power this firmware otherwise saves
// (see ../wiki/knowledge/hardware.md), so a normal unattended night is
// unaffected. Enable per-device over the serial command channel, which persists
// the choice in NVS; RT_STREAM_ENABLED_DEFAULT is only the value used before
// anything has ever been stored.
#define RT_STREAM_ENABLED_DEFAULT   false

// SoftAP by default — a bedside device with no network to join, and live
// physiological data that has no business on a home LAN. The SSID gets the last
// three MAC bytes appended so two units in one room are distinguishable.
#define RT_STREAM_SOFTAP            1
#define RT_STREAM_SSID_PREFIX       "ProtoSom-"
#define RT_STREAM_AP_CHANNEL        6
#define RT_STREAM_AP_MAX_CONN       2

// WPA2 password, derived per-device from the MAC and shown on the OLED, so it
// is neither blank nor the same on every unit. See rt_stream_password().
#define RT_STREAM_PASSWORD_PREFIX   "som"

// STA mode (join an existing network) — only used when RT_STREAM_SOFTAP is 0.
#define RT_STREAM_STA_SSID          ""
#define RT_STREAM_STA_PASSWORD      ""

#define RT_STREAM_PORT              80
#define RT_STREAM_WS_PATH           "/rt"

// One frame per 100 ms: 5 samples of each 50 Hz channel, 10 of ECG. Matches the
// cadence src_web/src/rt_store.ts is tuned for, and keeps a frame comfortably
// inside one TCP segment at ~4 KB of JSON.
#define RT_STREAM_FRAME_MS          100

// Queue depth in frames. 2 s of buffering: enough to ride out a retransmit,
// short enough that a wedged client is dropped rather than accumulating stale
// samples nobody will look at.
#define RT_STREAM_QUEUE_FRAMES      20

// Stop the radio after this long with no client connected.
#define RT_STREAM_IDLE_TIMEOUT_S    600

// ── Local time zone ───────────────────────────────────────────────────────────
// UK time: GMT in winter, BST (UTC+1) from last Sunday in March to last Sunday
// in October. SNTP sets the system clock to UTC; this POSIX TZ rule is what
// makes localtime_r() report the correct local wall-clock time.
#define LOCAL_TZ "GMT0BST,M3.5.0/1,M10.5.0"

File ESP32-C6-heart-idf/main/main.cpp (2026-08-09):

#include "config.h"
#include "sensors.h"
#include "battery_gauge.h"
#include "logger.h"
#include "rt_stream.h"
#include "display.h"
#include "time_sync.h"
#include "freertos/FreeRTOS.h"
#include "freertos/task.h"
#include "freertos/queue.h"
#include "driver/gpio.h"
#include "esp_log.h"
#include "esp_system.h"
#include <stdio.h>
#include <stdlib.h>
#include <time.h>

static const char *TAG = "main";

// ── Boot diagnostics ──────────────────────────────────────────────────────────
// Survives every reset except power loss, so it counts unattended reboots.
static RTC_DATA_ATTR uint32_t s_boot_count = 0;

// Which source set the system clock at boot ("RTC", "Serial", or "none") —
// shown on the display; see the RTC/time_sync block in app_main().
static const char *s_time_sync_source = "none";

// Shown on the LCD because the resets under investigation only happen when no
// serial monitor is attached.
static void show_reset_reason(void)
{
    const char *rr;
    switch (esp_reset_reason()) {
        case ESP_RST_POWERON:   rr = "POWER-ON";   break;
        case ESP_RST_SW:        rr = "SW-RESET";   break;
        case ESP_RST_PANIC:     rr = "PANIC";      break;
        case ESP_RST_INT_WDT:   rr = "INT-WDT";    break;
        case ESP_RST_TASK_WDT:  rr = "TASK-WDT";   break;
        case ESP_RST_WDT:       rr = "OTHER-WDT";  break;
        case ESP_RST_DEEPSLEEP: rr = "SLEEP-WAKE"; break;
        case ESP_RST_BROWNOUT:  rr = "BROWNOUT";   break;
        default:                rr = "OTHER";      break;
    }
    s_boot_count++;
    char msg[32];
    snprintf(msg, sizeof(msg), "RST:%s BOOT#%lu", rr, (unsigned long)s_boot_count);
    display_boot_msg(msg);
    ESP_LOGI(TAG, "Reset reason: %s, boot count %lu", rr, (unsigned long)s_boot_count);
}

// ── Serial time sync ─────────────────────────────────────────────────────────
// Called from the time_sync task on every accepted frame — at boot, and again
// whenever the host re-syncs mid-recording. The RTC write is what makes a
// mid-recording sync stick: sensor_task re-applies the RTC to the system clock
// every RTC_SYNC_INTERVAL_MS, which would otherwise undo the new time within
// ten minutes. The LED flash lives in the time_sync component itself.
static void on_time_sync(void)
{
    sensors_rtc_write_from_system();
    s_time_sync_source = "Serial";
}

// Recording duration after which the display is shut down (§ wake button below).
#define DISPLAY_SLEEP_AFTER_S (20 * 60)

// ── Display wake button (GPIO13, falling edge) ───────────────────────────────
// Wired to a momentary button to GND (internal pull-up enabled). Re-enables
// the display after display_sleep() has shut it down 20 minutes into a
// recording (see DISPLAY_SLEEP_AFTER_S below).
#define WAKE_BTN_PIN GPIO_NUM_13

static QueueHandle_t s_wake_evt_queue = NULL;

static void IRAM_ATTR wake_btn_isr(void *arg)
{
    (void)arg;
    BaseType_t hpw = pdFALSE;
    uint32_t dummy = 0;
    xQueueSendFromISR(s_wake_evt_queue, &dummy, &hpw);
    if (hpw) portYIELD_FROM_ISR();
}

static void wake_button_task(void *arg)
{
    (void)arg;
    uint32_t dummy;
    for (;;) {
        if (xQueueReceive(s_wake_evt_queue, &dummy, portMAX_DELAY) == pdTRUE) {
            ESP_LOGI(TAG, "Wake button pressed: re-enabling display");
            display_wake();
        }
    }
}

static void wake_button_init(void)
{
    s_wake_evt_queue = xQueueCreate(4, sizeof(uint32_t));

    gpio_config_t io_conf = {};
    io_conf.pin_bit_mask = 1ULL << WAKE_BTN_PIN;
    io_conf.mode         = GPIO_MODE_INPUT;
    io_conf.pull_up_en   = GPIO_PULLUP_ENABLE;
    io_conf.intr_type    = GPIO_INTR_NEGEDGE;
    gpio_config(&io_conf);

    gpio_install_isr_service(0);
    gpio_isr_handler_add(WAKE_BTN_PIN, wake_btn_isr, NULL);

    xTaskCreate(wake_button_task, "wake_btn", 4096, NULL, 5, NULL);
}

// ── Sensor / logger / display task (runs at 100 Hz) ──────────────────────────
static void sensor_task(void *arg)
{
    (void)arg;

    TickType_t       wake       = xTaskGetTickCount();
    const TickType_t period_ms  = pdMS_TO_TICKS(10);  // 100 Hz base tick

    int tick50   = 0;  // divides to 50 Hz
    int tick_disp = 0; // divides to 5 Hz
    int tick_rtc  = 0; // RTC drift-correction watchdog (in 50 Hz ticks)
    bool auto_sleep_triggered = false;

    while (1) {
        vTaskDelayUntil(&wake, period_ms);

        // 100 Hz: ECG ADC (AD8232, ADC channel 0)
        sensors_read_ecg();
        logger_record_ecg(g_ecg_raw);
        rt_stream_push_ecg(g_ecg_raw);

        // 50 Hz: all other sensors + logging + display
        if (++tick50 >= 2) {
            tick50 = 0;

            sensors_read();

            // BLE removed: HR/RR have no live source, logged as zero for now.
            logger_record(
                g_accel0_x, g_accel0_y, g_accel0_z,
                g_accel1_x, g_accel1_y, g_accel1_z,
                g_ldc0, g_ldc1,
                g_pressure_mbar,
                0);

            // Live stream tap. No-op unless streaming was enabled for this
            // device, and never blocks: a frame it cannot queue is dropped
            // rather than delaying the SD write above.
            rt_stream_push_50hz(
                g_accel0_x, g_accel0_y, g_accel0_z,
                g_accel1_x, g_accel1_y, g_accel1_z,
                g_ldc0, g_ldc1,
                g_pressure_mbar,
                0);

            // 5 Hz: display
            if (++tick_disp >= 10) {
                tick_disp = 0;

                // 20 minutes into a recording, shut the display down
                // completely (backlight off, panel asleep, no more draws)
                if (logger_is_active() &&
                    logger_get_elapsed_seconds() >= DISPLAY_SLEEP_AFTER_S &&
                    !auto_sleep_triggered) {
                    display_sleep();
                    auto_sleep_triggered = true;
                }
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

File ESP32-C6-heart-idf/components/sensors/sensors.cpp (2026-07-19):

#include "sensors.h"
#include "MMA8451.h"
#include "LDC1612.h"
#include "SDP800.h"
#include "DS3231.h"
#include "config.h"
#include "driver/i2c_master.h"
#include "esp_adc/adc_oneshot.h"
#include "esp_log.h"
#include "freertos/FreeRTOS.h"
#include "freertos/task.h"
#include <stdlib.h>
#include <time.h>
#include <sys/time.h>

static const char *TAG = "sensors";

// ── Globals ───────────────────────────────────────────────────────────────────
volatile int16_t  g_accel0_x, g_accel0_y, g_accel0_z;
volatile int16_t  g_accel1_x, g_accel1_y, g_accel1_z;
volatile uint32_t g_ldc0, g_ldc1;
volatile float    g_pressure_mbar;
volatile uint16_t g_ecg_raw;
volatile bool     g_rtc_present;
volatile bool     g_mma0_present;
volatile bool     g_mma1_present;
volatile bool     g_ldc_present;
volatile bool     g_sdp_present;

// ── I2C handles ───────────────────────────────────────────────────────────────
static i2c_master_bus_handle_t   s_i2c_bus;
static i2c_master_dev_handle_t   s_mma0, s_mma1, s_ldc, s_sdp, s_ds3231;
static adc_oneshot_unit_handle_t s_adc;

adc_oneshot_unit_handle_t sensors_get_adc_unit(void)
{
    return s_adc;
}

static esp_err_t add_dev(uint8_t addr, i2c_master_dev_handle_t *out)
{
    i2c_device_config_t cfg = {};
    cfg.dev_addr_length = I2C_ADDR_BIT_LEN_7;
    cfg.device_address  = addr;
    cfg.scl_speed_hz    = I2C_FREQ_HZ;
    return i2c_master_bus_add_device(s_i2c_bus, &cfg, out);
}

bool sensors_init(i2c_master_bus_handle_t bus)
{
    vTaskDelay(pdMS_TO_TICKS(50));  // wait for sensors to power up (SDP800 datasheet §3.2 says 25ms minimum)
    s_i2c_bus = bus;

    bool ok = true;

    g_mma0_present = (add_dev(MMA_ADDR_0, &s_mma0) == ESP_OK) && mma8451_init(s_mma0);
    if (!g_mma0_present) {
        ESP_LOGW(TAG, "MMA8451 #0 not found");
        ok = false;
    }
    else {
        ESP_LOGI(TAG, "MMA8451 #0 detected");
    }
    g_mma1_present = (add_dev(MMA_ADDR_1, &s_mma1) == ESP_OK) && mma8451_init(s_mma1);
    if (!g_mma1_present) {
        ESP_LOGW(TAG, "MMA8451 #1 not found");
        ok = false;
    }
    else {
        ESP_LOGI(TAG, "MMA8451 #1 detected");
    }
    g_ldc_present = (add_dev(LDC_ADDR, &s_ldc) == ESP_OK) && ldc1612_init(s_ldc);
    if (!g_ldc_present) {
        ESP_LOGW(TAG, "LDC1612 not found");
        ok = false;
    }
    else {
        ESP_LOGI(TAG, "LDC1612 detected");
    }
    g_sdp_present = (add_dev(SDP800_ADDR, &s_sdp) == ESP_OK);
    if (!g_sdp_present) {
        ESP_LOGW(TAG, "SDP800 device not found on address 0x%02X", SDP800_ADDR);
        ok = false;
    }
    else {
        g_sdp_present = sdp800_init(s_sdp);
        if (!g_sdp_present) {
            ESP_LOGW(TAG, "SDP800 detected but failed to initialize");
            ok = false;
        }
        else {
            ESP_LOGI(TAG, "SDP800 detected");
        }
    }


    // The RTC is optional (not fitted on every board), so its absence does
    // not fail sensors_init() the way the other sensors do.
    g_rtc_present = (add_dev(DS3231_ADDR, &s_ds3231) == ESP_OK);
    if (!g_rtc_present) {
        ESP_LOGW(TAG, "DS3231 RTC device not found on 0x%02X", DS3231_ADDR);
    }
    else {
        if (ds3231_init(s_ds3231)) {
            ESP_LOGI(TAG, "DS3231 RTC detected");
        }
        else {
            ESP_LOGW(TAG, "DS3231 RTC detected but failed to initialize");
            g_rtc_present = false;
        }
    }

    adc_oneshot_unit_init_cfg_t adc_cfg = {};
    adc_cfg.unit_id = ECG_ADC_UNIT;
    ESP_ERROR_CHECK(adc_oneshot_new_unit(&adc_cfg, &s_adc));
    adc_oneshot_chan_cfg_t ch_cfg = {
        .atten    = ADC_ATTEN_DB_12,
        .bitwidth = ADC_BITWIDTH_12,
    };
    ESP_ERROR_CHECK(adc_oneshot_config_channel(s_adc, (adc_channel_t)ECG_ADC_CHANNEL, &ch_cfg));

    return ok;
}

void sensors_read(void)
{
    mma8451_read(s_mma0, &g_accel0_x, &g_accel0_y, &g_accel0_z);
    mma8451_read(s_mma1, &g_accel1_x, &g_accel1_y, &g_accel1_z);
    g_ldc0          = ldc1612_read_channel(s_ldc, 0);
    g_ldc1          = ldc1612_read_channel(s_ldc, 1);
    // sdp800_read() returns Pascals (raw / on-chip scale factor, §6.5 of the
    // SDP810-125Pa datasheet); convert to mbar (1 mbar = 100 Pa) to match the
    // EDF+ Flow channel's declared physical dimension. Skip the read entirely
    // when init failed, rather than polling a sensor that was never told to
    // start continuous measurement.
    g_pressure_mbar = g_sdp_present ? sdp800_read(s_sdp) : 0.0f;
}

void sensors_read_ecg(void)
{
    int raw = 0;
    adc_oneshot_read(s_adc, (adc_channel_t)ECG_ADC_CHANNEL, &raw);
    g_ecg_raw = (uint16_t)raw;
}

// ── RTC (DS3231) time sync ──────────────────────────────────────────────────

// Reads the RTC and treats it as valid only once it holds a plausible time —
// i.e. it has already been set at least once (year >= 2026 rules out the
// power-up default of the DS3231's clock never having been set, or a dead
// battery having reset it to an earlier date).
static bool read_valid_rtc_time(struct tm *out)
{
    if (!g_rtc_present) return false;
    if (!ds3231_get_time(s_ds3231, out)) return false;
    return (out->tm_year + 1900) >= 2026;
}

// t is interpreted as UTC (this project always stores UTC in the RTC, same as
// what a serial time-sync frame carries). timegm() converts a UTC broken-down
// time directly, where mktime() would apply the local offset to it.
//
// This used to swap the global TZ to "UTC0" around a mktime() call and restore
// it afterwards. Two problems with that: every localtime_r() in any other task
// reported UTC for the width of the window, and once time_sync gained its own
// task — which can setenv("TZ", ...) from a host frame at any moment — the
// restore could revert a host-supplied zone to the previously saved one.
// timegm() touches no global state, so both go away.
//
// The old version also installed LOCAL_TZ as a side effect when TZ was unset.
// app_main() now sets it unconditionally at boot, which is where that belongs.
static void apply_utc_tm_to_system_clock(const struct tm *t)
{
    struct tm tmp = *t;
    tmp.tm_isdst = 0;  // UTC has no DST, and the DS3231 read leaves this unset

    struct timeval tv = { .tv_sec = timegm(&tmp), .tv_usec = 0 };
    settimeofday(&tv, NULL);
}

bool sensors_rtc_startup_sync(void)
{
    struct tm t;
    if (!read_valid_rtc_time(&t)) return false;

    apply_utc_tm_to_system_clock(&t);
    ESP_LOGI(TAG, "System clock set from RTC: %04d-%02d-%02d %02d:%02d:%02d UTC",
             t.tm_year + 1900, t.tm_mon + 1, t.tm_mday, t.tm_hour, t.tm_min, t.tm_sec);
    return true;
}

void sensors_rtc_write_from_system(void)
{
    if (!g_rtc_present) return;

    time_t now = time(NULL);
    struct tm t;
    gmtime_r(&now, &t);
    if (!ds3231_set_time(s_ds3231, &t)) {
        ESP_LOGW(TAG, "Failed to write time to RTC");
    }
}

void sensors_rtc_periodic_sync(void)
{
    struct tm t;
    if (!read_valid_rtc_time(&t)) return;
    apply_utc_tm_to_system_clock(&t);
}

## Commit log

2026-06-15 AD8232 interface via ESP32-S3 added
2026-06-15 moved the Arduino sketch into it's own folder, removed Python code, ESP32 now reads the BLE data directly from the Polar H9 heart rate sensor
2026-06-15 correct to 10 byte I2C packet
    [BLE_HR_plus_accel_ADC.ino, hr_i2c.cpp]
2026-06-15 always get HR changes from I2C buffer
2026-06-15 trying to read I2C but no luck. Will store on ESP32 instead
2026-06-15 saving to ESP32 instead
2026-06-15 no print during dumping
2026-06-15 now prints accel values
2026-06-17 ESP32 code refactored, and writes EDF file instead. I need to think about how best to manage file storage. I might utilise separate run-time compressed files for each metric, and assemble them into E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
2026-06-20 Tremor-Illustrated viewer: zarrita reader, per-channel bubble charts, Zarr fixture + tests, PWA
    src_web:
    - Scaffold to coding standards: pnpm, strict tsconfig, flat ESLint (functional rules), Vitest
    - Migrate zarr.js -> zarrita.js; read Zarr v2 + Blosc(zstd) over the boundary (WASM decode)
    - Tremor-Illustrated UI: per-channel "bubble" cards (own y-axis + time axis, full-width),
    data-driven PLMI gauge, KPI cards, montage rail; mobile tap-to-fullscreen (landscape) + touch-scroll
    - PWA: manifest, service worker (offline), icons
    tools/make_fixture.py: dev/oracle that writes a spec-compliant Zarr v2 + Blosc store
    (+ meta.json / events.json) from the legacy biometric_filtered.bin
    tests (15 gre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
2026-06-21 Enforce discipline: Husky hooks + ESLint functional pass
    ESLint green (0 problems):
    - functional-core rules (no-let, immutable-data, prefer-readonly-type,
    prefer-readonly-parameter-types) stay strict on the pure core
    (format / narrative / tokens / types)
    - scoped override relaxes them on the DOM/ECharts/Zarr I/O edge + tests
    (typed-array / DOM / option params, chart lifecycle)
    - auto-fixed array-type / optional-chain; hand-fixed restrict-template-expressions
    and unnecessary-optional-chain
    Husky (core.hooksPath=.husky):
    - pre-commit: lint-staged (eslint --fix on staged) + tsc --noEmit
    - pre-push: vitest
    - hooks cd into src_web (polyglot repo: TS project is a subdir);
    package.json p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
2026-06-21 Tighten viewer UI: squarer corners + full-width bubble charts
    - border radius 14 -> 4px (cards read near-square; pills unchanged)
    - per-bubble chart margins tightened (grid left/right 50/14 -> 38/8) and card
    side padding 12 -> 6px, so each waveform uses the full bubble width and the
    x-axis end label is visible
    - rebuilt bundle; bumped asset cache-bust
2026-06-23 Desktop viewer: taller charts + don't capture the wheel
    - double the per-channel plot height on desktop/tablet (.sig-plot 150 -> 300px;
    mobile <=760px stays 132px)
    - disable the inside-zoom wheel/drag capture on desktop so the page scrolls
    normally with the cursor over a chart (zoomOnMouseWheel / moveOnMouseWheel /
    moveOnMouseMove = false); crosshair + tooltip sync via axisPointer +
    echarts.connect is unaffected
    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
2026-06-24 merging hardware (in Kicad) into this repo. They are very closely tied together, and share a lot of knowledge
    [Accelerometer.kicad_sch, EEG.kicad_sch, IO.kicad_sch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]
2026-06-24 Fix wiki site after repo rename; explain the LLM wiki in the README
    The repo was renamed ProtoSom -> OpenPolysom, which left the Quartz build's
    baseUrl/basepath stale, so the explorer, graph, search and SPA navigation all
    linked to /ProtoSom/* and 404'd.
    - web/quartz.config.yaml: baseUrl -> sunrise-designs.github.io/OpenPolysom (this
    path sets the SPA basepath + the in-site link prefix, so it must match the repo
    name); footer GitHub link -> OpenPolysom
    - web/build.sh: rewrite INDEX.md link targets to index.md in the build copy
    (slugs are case-sensitive, so the renamed root was unreachable); point the
    repo-file (../../) links at the OpenPolysom blob URL
    - README.md: add a section exp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
2026-06-24 Unbreak the Husky hooks: run checks only when their tooling is installed
    Dmitry's minimal package.json (pnpm->npm) dropped lint-staged and the test script, but the committed hooks still called them, so every commit/push failed repo-wide. Make both hooks package-manager-agnostic and gate each check on its binary AND config/script existing; they no-op gracefully on a minimal checkout and reactivate automatically if the tooling is restored. tsc --noEmit still runs and passes.
2026-06-25 ported to ESP32-C6 target
2026-06-26 some new datasheets for the ESP32-C6 dev board
2026-06-26 some EEG hardware options added, like DIN 42802-1 1.5mm plugs and sockets
2026-06-26 ESP32-S3 code is now obsolete
2026-06-28 esp32 code fixes - builds now with idf 6.0.1
    [config.h, display.cpp, display.h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]
2026-06-28 refactoring to store all pin settings in Kconfig, and decouple the display components from dependency on sensor code
2026-06-28 remove redunant code which reads out files over UART - they are getting far too large, and we now store them on an SD card for direct read-out on the PC
    [logger.cpp, logger.h, main.cpp]
2026-06-28 refactor sensors into their individual device files
2026-07-01 pin assignments fixed
2026-07-01 correct the SD card select pin
2026-07-01 correct the datetime for BST, and write the ESP_LOGx to a file on SD card too
    [config.h, logger.cpp, logger.h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]
2026-07-01 fixed the inadequate RR sampling
    [logger.cpp]
2026-07-01 display issues fixed! hooray! It was a DMA race condition
    [display.cpp]
2026-07-02 potential reboot fix, display cause of reboot
    [display.cpp, display.h, main.cpp]
2026-07-02 ESP32-C6-LCD-1.47 reference data
2026-07-02 fix for BLE updates
    [display.cpp, display.h, logger.cpp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]
2026-07-07 include partitions table and update pinouts
    [partitions.csv]
2026-07-07 expose the SD card file contents over a WIFI access point so that the card does not need to be physically removed every time
    [partitions.csv]
2026-07-08 fixes to charts zooming and montage enable switches
2026-07-09 revert erroneous JTAG console printout
2026-07-09 faster sample rate for RR data, 2.5 Hz
2026-07-09 showing and scoring movement for both legs
2026-07-09 no longer using this code
    [BLE_HR_plus_accel_ADC.ino, LDC1612.cpp, LDC1612.h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]
2026-07-09 multi-study landing page has, erm, landed
2026-07-09 sorted out baseline and scaling issues with the sensors
2026-07-09 flow scaling and RIP division fixed
    [logger.cpp, sensors.cpp]
2026-07-09 put the display to sleep after 20 mins to save power
2026-07-09 deploy script fixed - now shows the list of studies in the landing page
2026-07-09 - re-enabled AP file server, - show air flow data on the display - show a very simple battery gauge
2026-07-09 battery adc pin matches the physical connection to GPIO3
2026-07-12 big refactor: - do away with BLE - now reading raw ECG from AD8232 sensor (which needs 3 electrodes) - remove file Access Point, which never worked anyway. In this new hardware revision, SD card is m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
2026-07-12 removed wifi ntp sync and replaced it with much simpler sync over serial from a PC
    [config.h, display.cpp, display.h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]
2026-07-13 renamed depreciated to Deprecated with correct word spelling (and meaning!)
    [BLE_HR_plus_accel_ADC.ino, LDC1612.cpp, LDC1612.h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]
2026-07-13 corrected the pin assignment at the root
2026-07-13 hardware info and 3D added
    [Respeaker2MicPiHat.step]
2026-07-15 a few hardware issues fixed
    [battery_gauge.c, main.cpp, sensors.cpp]
2026-07-15 pins corrected where it matters, also moved away from Kconfig which I keep forgetting to update
    [config.h, wifi_ntp.cpp]
2026-07-16 sorted SDP sensor mis-comms
2026-07-17 changed the RTC clock to a part that supports 3V3, not 5V!
2026-07-17 added code to distinguish gross positional changes from leg jerks
2026-07-17 added diag for SD card write failures
    [logger.cpp, logger.h]
2026-07-19 interrupt-driven serial command server
2026-07-19 time zone and time sync now work correctly
    [logger.cpp, main.cpp, sensors.cpp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]
2026-08-20 remove legacy Raspberry Pi references completely
